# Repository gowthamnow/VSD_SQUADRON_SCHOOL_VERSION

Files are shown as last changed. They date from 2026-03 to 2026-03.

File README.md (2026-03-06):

# 🏰 VSD Squadron School Version - Technical Whitepaper & Git Repo

This repository serves as a comprehensive engineering showcase for a Micromouse robot built around the **VSD Squadron FM FPGA**. It transitions from high-level architectural concepts to bit-precise RTL implementation and high-fidelity PCB design.

---

## 📸 Media & Process Gallery

### 🤖 The Fabricated Robot
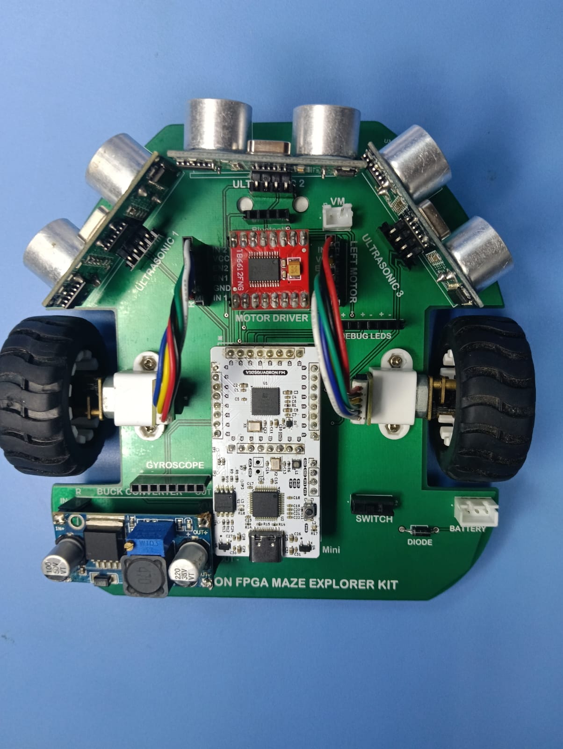
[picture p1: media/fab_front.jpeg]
Front
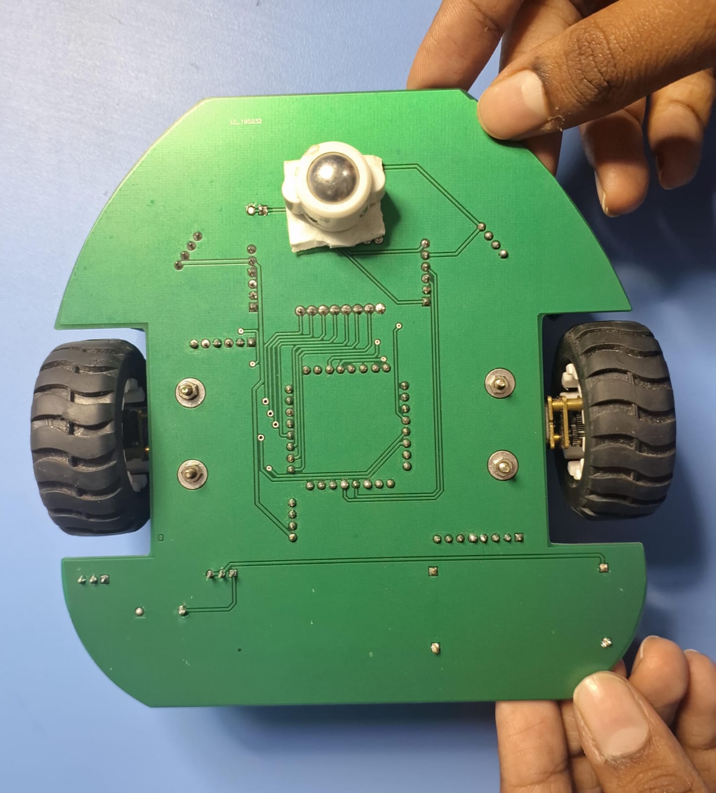
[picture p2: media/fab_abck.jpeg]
Back
|  |  |
| :---: | :---: |
| *Front View: Sensor Array & Chassis* | *Back View: Motor Drivers & Power* |

### 🎬 Performance Validation
| [Maze Navigation 1](media/mazefirst.mp4) | [Maze Navigation 2](media/maze2.mp4) |
| :---: | :---: |

---

## ⚡ RTL Architecture Deep-Dive

The system logic is implemented in **Verilog HDL**, optimized for the **Lattice iCE40** fabric found on the VSD Squadron FM.

### 1. Ultrasonic Ranging Core (`ultra_sonic_sensor.v`)
The ranging core operates as a synchronous state machine clocked at 12MHz.

#### 🛰️ State Machine Analysis (FSM)
```mermaid
stateDiagram-v2
    [*] --> IDLE
    IDLE --> TRIGGER : measure == 1
    TRIGGER --> WAIT : 10us elapsed
    WAIT --> COUNTECHO : echo == 1
    COUNTECHO --> IDLE : echo == 0
```
- **IDLE (2'b00)**: Waiting for the `measure` pulse from the `refresher250ms` module.
- **TRIGGER (2'b01)**: Asserting the `trig` pin. The `parameter ten_us = 10'd120` ensures an exact 10µs pulse (120 cycles @ 12MHz).
- **WAIT (2'b11)**: Synchronization state waiting for the HC-SR04 driver to initiate the ultrasonic burst.
- **COUNTECHO (2'b10)**: The core timing loop. `distanceRAW` increments every clock cycle while `echo` is high.

#### 📐 Precision Ranging Math
To convert raw cycles into centimeters without floating-point hardware:
$$Distance(cm) = \frac{Cycles \times 34300 \frac{cm}{s}}{2 \times 12,000,000 \frac{cycles}{s}}$$
This is implemented using high-precision fixed-point multiplication before the division to maintain accuracy.

### 2. UART Telemetry Interface (`uart_trx.v`)
An **8N1 (8 data bits, No parity, 1 stop bit)** transmitter for real-time telemetry.

- **Baud Rate Generation**: The module expects a baud-aligned clock (9600Hz).
- **State Transition**:
  1. `STARTTX`: Pulls line LOW.
  2. `TXING`: Iterates through `buf_tx[7:0]` using a bit counter.
  3. `TXDONE`: Drives line HIGH (Idle/Stop) for 1 bit period.

---

## 🚥 Hardware Engineering & PCB Design

### 1. The VSD Squadron FM Footprint
Designing the footprint required sub-millimeter precision to accommodate the 36-pin DIP-style FPGA module.
- **Pitch**: 2.54mm (100 mil) standard header.
- **Span**: Optimized for a 600 mil row-to-row spacing.
- **Via Design**: 0.9mm drill size for robust mechanical mounting and ease of hand-soldering.

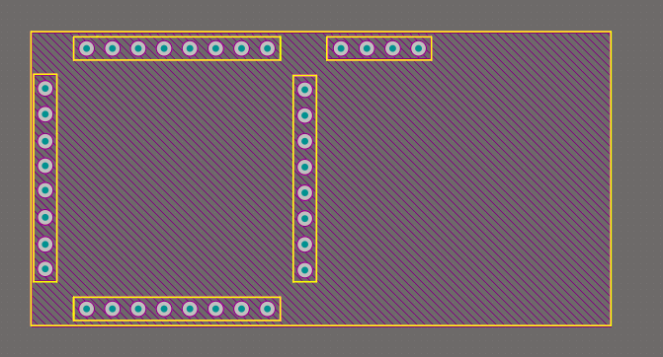
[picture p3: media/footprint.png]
Footprint


### 2. Schematic Rationale
- **Power Tree**: A dual-rail supply system. The Li-ion battery (7.4V) is regulated down to **5V** for the Ultrasonic sensors and then further to **3.3V** for the FPGA core and logic.
- **Level Shifting**: The HC-SR04 ECHO pulse is 5V, while the iCE40 I/Os are 3.3V. A simple voltage divider (1kΩ/2kΩ) is utilized to ensure signal integrity without damaging the FPGA fabric.

| 2D Design | 3D Visualization |
| :---: | :---: |
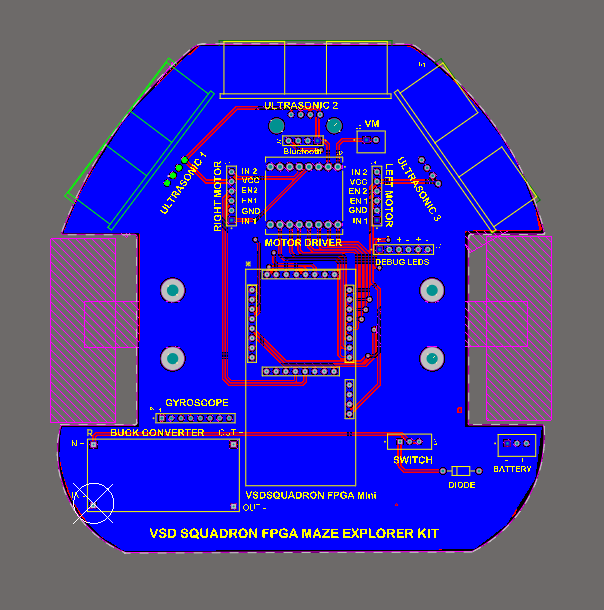
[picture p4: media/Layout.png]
Layout
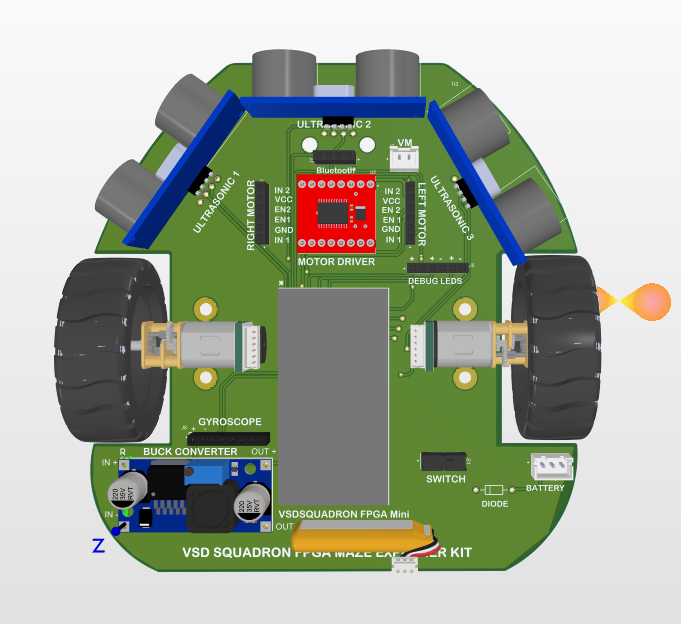
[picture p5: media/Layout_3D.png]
3D View
|  |  |

---

## 🛠️ Toolchain & Deployment Guide

This project leverages the open-source **IceStorm** toolchain for a streamlined "Code-to-Bitstream" workflow.

### 1. Synthesis & PnR Flow
1. **Synthesis**: `yosys -p "synth_ice40 -top top_module -json project.json" rtl/*.v`
2. **Place & Route**: `nextpnr-ice40 --lp8k --package cm81 --json project.json --pcf rtl/VSDSquadronFM.pcf --asc project.asc`
3. **Bitstream**: `icepack project.asc project.bin`
4. **Flash**: `iceprog project.bin`

### 2. Physical Constraints (`.pcf`)
The `.pcf` file is the bridge between the logic and the PCB.
```pcf
set_io hw_clk 20       # 12MHz On-board Osc
set_io echo1 2         # Front Ultrasonic Echo
set_io trig1 3         # Front Ultrasonic Trig
set_io AIN1 19         # Left Motor Dir A
set_io PWMA 31         # Left Motor Speed
```

---

## 🎓 Conclusion
This Micromouse implementation stands as a testament to the versatility of the **VSD Squadron FM**. By offloading time-critical sensing and motor control to dedicated RTL blocks, we achieve microsecond-level responsiveness that is unattainable with standard microcontrollers.

**Developed by**: Gowtham  
**Platform**: VSD Squadron FM (iCE40-based)

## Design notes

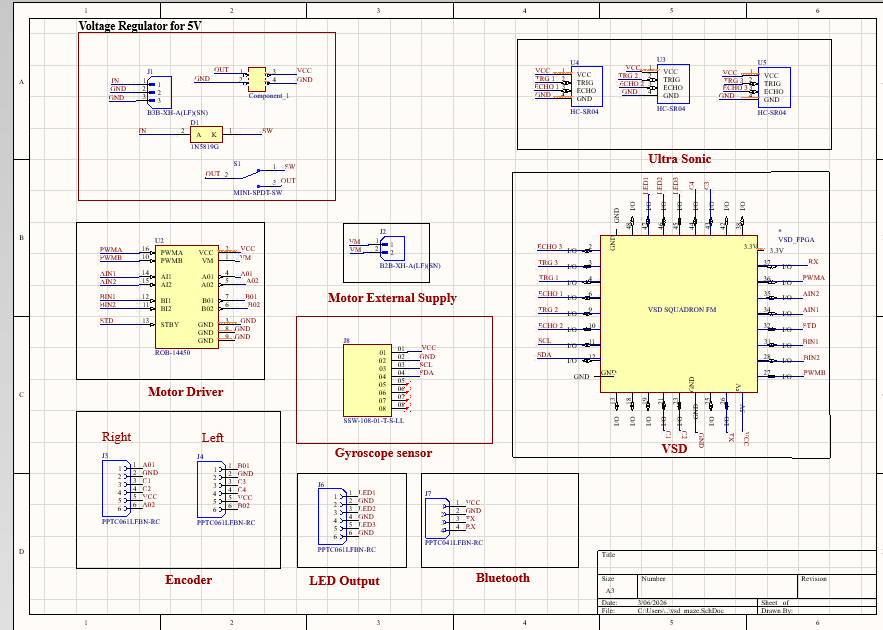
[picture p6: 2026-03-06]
media/schematics.png

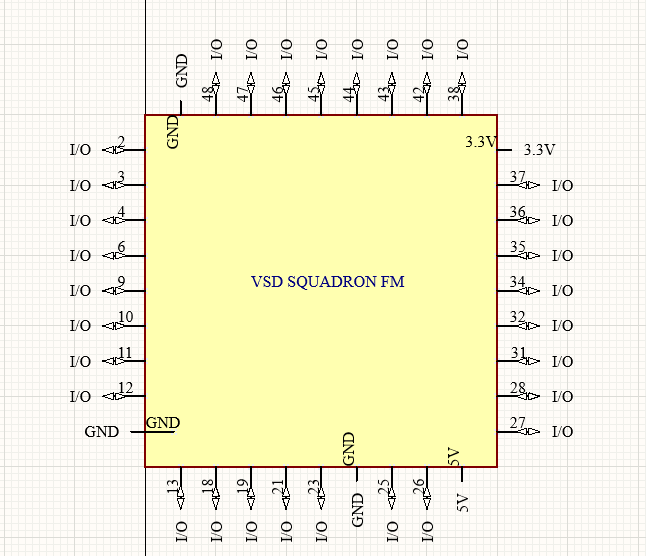
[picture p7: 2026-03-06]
media/symbol.png

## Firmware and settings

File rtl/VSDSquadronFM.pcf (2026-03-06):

set_io uarttx 14
set_io uartrx 15
set_io hw_clk 20

# Ultrasonic Sensor 1
set_io echo1 2
set_io trig1 3
set_io led1 4

# Ultrasonic Sensor 2
set_io echo2 9
set_io trig2 6
set_io led2 10

# Ultrasonic Sensor 3
set_io echo3 13
set_io trig3 12
set_io led3 18

# Motor Control
set_io AIN1 19
set_io AIN2 21
set_io BIN1 27
set_io BIN2 28
set_io PWMA 31
set_io PWMB 32
set_io STBY 34
